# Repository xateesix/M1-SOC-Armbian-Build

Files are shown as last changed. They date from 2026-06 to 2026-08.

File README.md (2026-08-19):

# A3D M1 Pro X1  -  Armbian eMMC Firmware (RK3308BS)

**v0.64.1**  -  experimental firmware for the Artillery M1 Pro S1-SOC control board.

## Project intent

Turn an **otherwise barely usable or unusable** Artillery M1 Pro X1 into a **current mainline Klipper** printer by splitting roles across **new motion hardware** and the **factory S1-SOC board**.

| Role | Hardware | Target software |
|---|---|---|
| **Printer / motion (heavy lifting)** | New **host + CNC Mainboard with new toolhead board** (e.g. [BTT Manta M4P](https://www.biqu.equipment/products/bigtreetech-manta-m4p) + [FYSETC H36](https://www.fysetc.com/products/fysetc-h36-mainboard)) | Mainline **Klipper** on the MCU stack  -  motion, heaters, fans, probe |
| **Display + camera node** | Factory **RK3308 S1-SOC** (this firmware) | **KlipperScreen** on the stock LCD, **Crowsnest** for webcam streaming |

The S1-SOC is **not** the printer MCU. It is an **external companion**  -  UI and camera  -  while the new host + toolhead boards run Klipper for the machine.

This is a **work in progress** [incomplete] (Z-stop/probe on the motion stack, KlipperScreen/Crowsnest integration on the S1-SOC).

> ## WARNING  -  READ FIRST
>
> - **Experimental**  -  not supported by Artillery 3D; no warranty.
> - **Void warranty**  -  flashing and hardware mods void manufacturer warranty.
> - **Dangerous voltages**  -  mains AC and 24 V DC. Fire and shock risk.
> - **Extra hardware**  -  USB-C **data** cable, USB-TTL serial adapter (FT232RL), Windows PC with RKDevTool, MASKROM recovery access, plus the **host + toolhead upgrade** for printer control.
> - **You assume all risk**  -  authors are not liable for damage or injury.
>
> Full text: [`docs/WARNING.md`](docs/WARNING.md)

> **Hardware upgrade required for printing:** Motion and Klipper MCU duties need a **3/4-axis host** and **toolhead board** (see below). This S1-SOC image is for the **companion display/camera node**. Repinning JST connectors and high-voltage work can **destroy hardware** or **cause fire**. See [`docs/UPGRADE_PATH.md`](docs/UPGRADE_PATH.md).

## Target architecture (read before flash)

### Motion stack (required for Klipper printing)

| Part | Example |
|---|---|
| **Host** (3 or 4 axis + Klipper MCU) | [BIGTREETECH Manta M4P](https://www.biqu.equipment/products/bigtreetech-manta-m4p) |
| **Toolhead / CNC board** | [FYSETC H36](https://www.fysetc.com/products/fysetc-h36-mainboard) |

This combo does the **heavy lifting**  -  steppers, hotend, bed, probe, and mainline Klipper firmware on the MCU.

**Work in progress:** **Z-stop / Z-probe** still required. Current direction: **Sovol Eddy** in a **custom housing** on the front print head cover. The H36 is chosen for high-temp rating, **3-wire PWM** fan headers, enough GPIO for current and future hardware, and [hopefully] **sideways fit** inside the print head cover.

Details: [`docs/UPGRADE_PATH.md`](docs/UPGRADE_PATH.md).

### 3D printed parts (required for rebuild)

| Part | STEP model |
|---|---|
| Manta M4P mounting bracket | [`models/M4P_M1Pro_Mounting_bracket.step`](models/M4P_M1Pro_Mounting_bracket.step) |
| Power supply relocate bracket | [`models/M1-PowerSupply-Relocate.step`](models/M1-PowerSupply-Relocate.step) |

Print from the STEP files or export STL in your CAD tool. Details: [`docs/UPGRADE_PATH.md`](docs/UPGRADE_PATH.md).

### S1-SOC companion (this repository)

Flash this repo's image on the **factory S1-SOC** to drive:

- **KlipperScreen** on the built-in **480x272** display
- **Crowsnest** for USB webcam streaming to your Klipper stack

The companion talks to your **real Klipper host** (Moonraker on the Manta side) over the network. It does **not** replace the motion boards.

Configuration guide (KlipperScreen  ->  Moonraker IP, Crowsnest on companion, Mainsail/Fluidd webcam URL): [`docs/COMPANION_SETUP.md`](docs/COMPANION_SETUP.md).

Skilled **JST repinning**, **mains / 24 V** awareness, and acceptance of serious risk are required. See [`docs/WARNING.md`](docs/WARNING.md).

## What this is

Experimental **Armbian eMMC firmware** for the **RK3308BS S1-SOC** on the Artillery M1 Pro X1. It replaces the factory Linux image with a lean OS intended as a **KlipperScreen + Crowsnest companion node**, using the stock display and WiFi.

This repository provides the **companion-board firmware and build pipeline**, not the main Klipper MCU firmware for the Manta/H36 stack.

## Media (in this repository)

| Asset | File |
|---|---|
| Hardware overview video (~45 MB) | [`Media/VID_20260615_141308204.mp4`](Media/VID_20260615_141308204.mp4) |
| Boot logo source (BMP) | [`Media/boot-logo-artillery.bmp`](Media/boot-logo-artillery.bmp) |

The custom boot logo is compiled into boot assembly by `tools/build-armbian-bootimg.sh`.

Board overview and control-header pin identification (case light bar, RGB JST, +LED-).
## USB-C data cable (required for flash)

MASKROM flashing and RKDevTool need a **data-capable** USB connection from your PC to the control board USB port.

| Need | Detail |
|---|---|
| **Cable** | Good-quality **USB-C data cable** (USB-C to USB-A or USB-C, matching your PC) |
| **Not sufficient** | Charge-only cables, many cheap phone cables, or long/under-spec cables |
| **Symptom if wrong** | RKDevTool never sees the device, or download fails mid-flash |

Use a cable rated for **data + power**. Short, branded or known data cables are more reliable than generic charge cords. If flash is unstable, try another cable and USB port before changing firmware.

## RKDevTool (required on Windows)

Rockchip firmware flash and the final eMMC **pack** step both use **RKDevTool** on a **Windows PC**. This repository does not bundle RKDevTool.

| Need | Detail |
|---|---|
| **Tool** | RKDevTool (v2.86 or newer recommended)  -  includes `RKDevTool.exe` for flashing and `bin/AFPTool.exe` + `bin/RKImageMaker.exe` for packing |
| **Driver** | Rockchip USB driver via **DriverAssistant** (install before first flash) |
| **Use** | **Upgrade Firmware** tab with a monolithic `.img` (not balenaEtcher / raw `dd`) |
| **USB cable** | Good-quality **USB-C data cable** (see section above) |
| **Recovery** | Board in **MASKROM** (recovery button / maskrom pads + USB) |

**Download and documentation:**

- **Firefly** (ROC-RK3308-CC / RK3308): [Resource downloads (RKDevTool)](https://en.t-firefly.com/doc/download/53.html)  -  [Burning firmware guide](https://wiki.t-firefly.com/en/ROC-RK3308-CC/burning_firmware.html)
- **Radxa** (Rockchip tools): [RKDevTool documentation](https://docs.radxa.com/en/zero/zero3/low-level-dev/rkdevtool)  -  [Windows tools download](https://dl.radxa.com/tools/windows/) (`RKDevTool_Release_v2.86.zip`, `DriverAssistant`)

After installing, run `RKDevTool.exe` as Administrator. Flash steps: [`FLASH_RKDEVTOOL.md`](FLASH_RKDEVTOOL.md).

## USB serial adapter (recommended)

A **USB to TTL serial adapter** lets you see boot logs and log in when WiFi or the display are not set up.

| Need | Detail |
|---|---|
| **Adapter** | FTDI **FT232RL** USB-TTL (3.3 V logic)  -  e.g. [DSD TECH SH-U09C](https://www.amazon.com/DSD-TECH-Adapter-FT232RL-Compatible/dp/B07BBPX8B8) |
| **Level** | Set adapter jumper to **3.3V** (RK3308 UART is 3.3 V TTL) |
| **Wiring** | GND  ->  GND, adapter TXD  ->  board RX, adapter RXD  ->  board TX (UART3 header) |
| **Baud** | **1500000** |
| **Console** | **`ttyS3`** on recovered v67 artifacts (older factory notes mention `ttyFIQ0`) |

Use PuTTY, Tera Term, or `picocom` at **1500000 8N1**. FTDI VCP drivers: [ftdichip.com](https://ftdichip.com/drivers/vcp-drivers/).

Full wiring and terminal notes: [`docs/SERIAL_CONSOLE.md`](docs/SERIAL_CONSOLE.md).

## Download and flash (companion image)

Host-role rule: if build and flash are on different machines, upload the image to the flashing machine first and run flash there. Do not run `upgrade_tool` or `rkdeveloptool` on the build machine.

1. From **GitHub Releases**, download `rk3308bs-1.0.0-emmc-fixed-v64.img`

Release: [v0.64.1](https://github.com/xateesix/M1-SOC-Armbian-Build-scripts-public/releases/tag/v0.64.1) — `rk3308bs-1.0.0-emmc-fixed-v64.img` and `build-artifacts-v0.64.1.tar.gz`.
2. Flash with RKDevTool  ->  **Upgrade Firmware**
3. **Change the default password** on first login

| Account | Username | Default password |
|---|---|---|
| Normal user | `m1prox1` | `m1prox1` |
| Root | `root` | `m1prox1` |

WiFi is **not** configured on the published image; build-time preconfigure is optional.

Release assets: [`docs/RELEASE.md`](docs/RELEASE.md)

## Build from source (GPL / customization)

Source code and build scripts are in this repository. Large binaries are on **GitHub Releases** as `build-artifacts-v0.64.1.tar.gz`.

The v64 pipeline **repatches and repacks** those inputs for the **S1-SOC companion image**.

### Build requirements

| Component | Notes |
|---|---|
| **Linux / WSL2** | Ubuntu recommended  -  patch, boot build, staging |
| **Windows + RKDevTool** | Final pack step  -  see RKDevTool section above |
| **Serial** | USB-TTL adapter (FT232RL, 3.3 V)  -  see section above |

### Steps

```bash
git clone <this-repository-url>
cd <repository-directory>

./configure.sh
bash setup-validate.sh
bash tools/build-release-v64.sh
```

Output: `releases/1.0.0/rk3308bs-1.0.0-emmc-fixed-v64.img`

### What the scripts verify

| Script | Role |
|---|---|
| `install-build-deps.sh` | Host packages and tools |
| `fetch-build-sources.sh` | Release tarball inputs |
| `preflight-v64.sh` | Linux deps + tarball |
| `setup-validate.sh` | Runs `preflight-v64.sh` |

## Configuration

| File | Purpose |
|---|---|
| `config.env.example` | Defaults  -  safe to commit |
| `configure.sh` | Interactive `config.env` setup |
| `config.env` | **Local only**  -  never commit |

## Feature status (v0.64.1)

| Feature | Status |
|---|---|
| S1-SOC companion image (boot, display, serial, WiFi base) | Working / WIP |
| 480x272 display + boot logo | Working |
| Serial `ttyS3` @ 1500000 | Working (older factory notes mention `ttyFIQ0`) |
| WiFi (RTL8189FS) | On-device or custom rebuild |
| **KlipperScreen** (companion role) | Target  -  integration WIP |
| **Crowsnest** (companion role) | Target  -  integration WIP |
| Main Klipper MCU (Manta M4P + H36) | **Required separate upgrade**  -  not this image |
| Z-stop / bed probe (motion stack) | **WIP**  -  Sovol Eddy + custom cover mount |
| Case light bar (+LED-) | Pin identified; driver in progress |
| RGB pebbles (WS2812) | Not supported |
| Factory Makerbase UI | Not included |

GPIO map: [`docs/GPIO_AND_HARDWARE.md`](docs/GPIO_AND_HARDWARE.md)
Boot logo: [`docs/BOOT_LOGO.md`](docs/BOOT_LOGO.md)

The image build now stages KIAUH, Klipper, Moonraker, KlipperScreen, and Crowsnest source trees during rootfs customization.

## Build pipeline

```text
configure.sh  ->  config.env (BUILD_ARTIFACTS_URL)
fetch-build-sources.sh  ->  tarball + partition templates
preflight-v64.sh  ->  verify Linux deps + inputs

build-release-v64.sh
  |-- build-boot-v64.sh
  |-- patch-rootfs-v64-debugfs.sh
  |-- stage-pack-v64.sh
  -- windows-pack-update.ps1
```

## Repository layout

| Path | Description |
|---|---|
| `configure.sh` | Interactive configuration |
| `setup-validate.sh` | Pre-build verification |
| `tools/` | v64 companion image build scripts |
| `patches/` | Kernel and DTS patches (GPL) |
| `models/` | Required 3D printed bracket STEP files |
| `docs/` | User documentation |
| `releases/` | Build output (git-ignored) |

## License and disclaimer

GPL-licensed components remain under their respective licenses. Provided as-is for research and self-hosting. Not affiliated with Artillery 3D.

## Changelog

See [`CHANGELOG.md`](CHANGELOG.md).

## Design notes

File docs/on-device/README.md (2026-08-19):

# On-device documentation (v0.64.1)

Companion firmware for the Artillery M1 Pro X1 S1-SOC (RK3308BS). Additional guides are in this folder.

## Login credentials

Change passwords after first boot.

| Account | Username | Password |
|---|---|---|
| Normal user | `m1prox1` | `m1prox1` |
| Root | `root` | `m1prox1` |

WiFi is **not** pre-configured on the published image.

## Repository media

| Asset | Path on SD/eMMC |
|---|---|
| Hardware overview video | Not on device — see repo [`Media/VID_20260615_141308204.mp4`](https://github.com/xateesix/M1-SOC-Armbian-Build-scripts-public/blob/main/Media/VID_20260615_141308204.mp4) |

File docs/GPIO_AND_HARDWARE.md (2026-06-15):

# GPIO map

Confirmed: case light bar = GPIO2_B3 (gpiochip2 line 11, gpio75), 24 V enable.
RGB NeoPixel: not supported v0.64.1.
Serial console: ttyFIQ0 @ 1500000  -  see docs/SERIAL_CONSOLE.md.

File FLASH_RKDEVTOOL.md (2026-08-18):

# RK3308BS  -  RKDevTool flash guide (Artillery M1 Pro S1-SOC)

## Host role rule (mandatory)

- Build host and flash host are different roles.
- Never run `upgrade_tool` or `rkdeveloptool` on the build host.
- Always upload firmware image from build host to flash host first, then flash on flash host.

Linux flash-host example (SSH alias `flashpc`):

```bash
IMG="rk3308bs-1.0.0-v64-from-source-linux-emmc.img"
SRC="/home/xateesix/scratch/Projects/rk3308bs-workspace/M1-SOC-Armbian-Build/releases/v64-from-source-linux/$IMG"

rsync --partial --append-verify "$SRC" flashpc:~/rk3308bs-firmware/
ssh flashpc "sha256sum ~/rk3308bs-firmware/$IMG"
ssh flashpc "sudo upgrade_tool uf ~/rk3308bs-firmware/$IMG"
```

## Install RKDevTool (not included in this repo)

Use a **Windows PC**. Download RKDevTool and the Rockchip USB driver from vendor tool pages:

| Source | Links |
|-----|----|
| **Firefly** | [RKDevTool download](https://en.t-firefly.com/doc/download/53.html)  -  [ROC-RK3308-CC burning guide](https://wiki.t-firefly.com/en/ROC-RK3308-CC/burning_firmware.html) |
| **Radxa** | [RKDevTool docs](https://docs.radxa.com/en/zero/zero3/low-level-dev/rkdevtool)  -  [Windows tools](https://dl.radxa.com/tools/windows/) |

Recommended: `RKDevTool_Release_v2.86.zip` plus **DriverAssistant**. Install the driver first, then run `RKDevTool.exe` as Administrator.

## USB cable

Use a **good-quality USB-C data cable** between the PC and the board USB port. Charge-only or poor cables often prevent MASKROM detection or cause failed downloads. Try a short, known data cable and a direct motherboard USB port if RKDevTool does not see the device.

## Use Upgrade Firmware + monolithic `.img`

1. Enter **MASKROM** (recovery button / maskrom pads + USB).
2. Open **RKDevTool**.
3. Tab: **Upgrade Firmware** (second tab).
4. **Firmware:** browse to a single monolithic `.img` file.
   - Do **not** load a custom `config.cfg` with separate partition files.
   - Do **not** use **Advanced  ->  Write by address**.
5. Click **Upgrade** / **Run**.
6. Watch the log  -  you **must** see:
   - `Download Boot Success`
   - `Download IDB Success`
   - `Download Firmware Start` with **`Gpt=1`**
   - `Start to download rootfs, offset=0x...` (multi-minute write for large images)
   - `Download Firmware Success` (ret=0, not `ret=1`)
7. Unplug USB, power cycle.

If **Download Boot** fails to start:

- **Advanced**  ->  **Download Loader**  ->  use `MiniLoaderAll.bin` from your partition templates or factory extract
- Immediately repeat step 5 on **Upgrade Firmware** with the **full** `.img`.

---

## Factory reference image

Known-good monolithic package (use for recovery and as packaging reference):

```
KLP_IMG_ARTILLERY_M1_PRO_S1-SOC_20251126_Beta (1)/KLP_IMG_ARTILLERY_M1_PRO_S1-SOC_20251126_Beta.img
```

Unpacked structure matches our repacks:

| Component | Factory | Our repacks |
|---|---|---|
| `boot.bin` (MiniLoader) | 321870 bytes | **identical** |
| `package-file` layout | standard Rockchip | **identical** |
| `parameter.txt` | `TYPE: GPT`, `MAGIC: 0x5041524B` | same format |
| RKImageMaker wrap | `-RK3308` + `-os_type:androidos` | same (`windows-pack-update.ps1`) |

If factory `.img` works on Upgrade but a custom `.img` does not, the problem is **not** the tab  -  check the log for the failure patterns below.

---

## Images

| File | When to use |
|---|---|
| `KLP_IMG_ARTILLERY_..._Beta.img` | **Recovery**  -  known-good factory |
| `SMOKE_v2_repack_only.img` | Validate repack pipeline (factory contents) |
| `rk3308bs-1.0.0-emmc-fixed.img` | Symlink/copy of **latest built** `-vNN.img` (currently **v43** if v45 not built yet) |
| `rk3308bs-1.0.0-emmc-fixed-v43.img` | **Do not use**  -  rootfs baked with `debugfs set_inode_field`  ->  `bogus i_mode` login loop |
| `rk3308bs-1.0.0-emmc-fixed-v45.img` | **Build this next**  -  safe chroot + `/boot/system.cfg` (no v44 image was ever produced) |
| `rk3308bs-1.0.0-emmc-fixed-v42.img` | Last good kernel/display before v43 rootfs patch (no WiFi grow stack) |
| `rk3308bs-1.0.0-emmc-fixed-v14.img` | Old baseline  -  v13 thermal + built-in DRM, no custom WiFi/LCD module load |
| `rk3308bs-1.0.0-emmc-fixed-v13.img` | v11 serial + factory RK3308BS TSADC  -  **do not use** (reboot breaks GPT; LCD blank) |
| `rk3308bs-1.0.0-emmc-fixed-v12.img` | v11 serial + **no thermal emergency reboot** (soc-crit passive workaround) |
| `rk3308bs-1.0.0-emmc-fixed-v11.img` | Factory DTB + ttyS3 serial  -  **still thermal reboot loop on 6.18** |

**Do not use an old `-emmc-fixed.img` from before 2026-06-11**  -  those had a broken `boot.img` header (resource.img in wrong slot  ->  U-Boot PXE/`=>` prompt).

Factory GPT layout (reference):

| # | LBA | Size | Name |
|---|-----|---|---|
| 1 | 0x2000 | 0x1000 | uboot |
| 2 | 0x3000 | 0x1000 | trust |
| 3 | 0x4000 | 0x800 | misc |
| 4 | 0x4800 | 0xa000 | recovery |
| 5 | 0xe800 | 0x4800 | boot (9 MB factory) |
| 6 | 0x13000 | grow | rootfs |

The `-fixed` Armbian image expands boot to **17 MB** (`0x8a00`) and moves rootfs to `0x17200`  -  required for Armbian 6.18 `boot.img`. Upgrade with `Gpt=1` rebuilds GPT from `parameter.txt` inside the package.

---

## Working flash log (June 4  -  factory, Upgrade tab)

```
Download Boot Success
Download IDB Success
Download Firmware Start
  Gpt=1, DirectLBA=1
  Start to download trust, offset=0x3000
  Start to download uboot, offset=0x2000
  Start to download boot,   offset=0xe800
  Start to download rootfs, offset=0x13000   Ã¢â€ Â ~5 GB, several minutes
  Start to download recovery, offset=0x4800
  Start to download misc, offset=0x4000
Download Firmware Success
Reset Device Success
```

---

## Broken flash patterns (June 9  -  do NOT do this)

### Pattern A  -  Write by address / custom config

```
Download parameter at 0x00000000 ...     Ã¢â€ Â destroys GPT at LBA 0
RunProc is ending, ret=1
ERROR: GetParameter_Loader->Check parameter tag failed!
```

Cause: **Advanced  ->  Write by address**, or a `config.cfg` that lists `parameter`, `uboot`, `boot`, etc. as separate files instead of one monolithic `.img`.

### Pattern B  -  partial partition list without Gpt=1

```
Download uboot at 0x00002000 ...
Download trust at 0x00003000 ...
Download boot at 0x0000e800 ...
Download armbian-serial-soc at 0x00000000 ...   Ã¢â€ Â wrong item at LBA 0
RunProc is ending, ret=1
```

Cause: custom config pointing at loose `.img`/`.bin` files (not the monolithic update package).

### Pattern C  -  flash too fast

Flash finishes in under ~30 seconds on a multi-GB image  ->  only loader/IDB written, not full firmware.

---

## What each symptom means

| Symptom | Cause |
|---|-----|
| Instant MASKROM, no button | IDB / boot sectors corrupt (bad or partial flash) |
| No partition table in MASKROM | GPT never created (`Gpt=1` path not run) |
| U-Boot `=>` + pxelinux / PXE | Boot partition empty, **truncated boot.img**, or **broken boot.img header** |
| `boot partition is not enough to save image!` | Use `rk3308bs-1.0.0-emmc-fixed.img` (17 MB boot slot) |

---

## Serial

After successful recovered v67 flash: **UART3 @ 1500000**, console **`ttyS3`** (older factory notes mention `ttyFIQ0`).

Verify:

```bash
cat /etc/rk3308bs-release
```

---

## PXE / `=>` prompt after Armbian flash (troubleshooting)

That output means **U-Boot never started the kernel**  -  it is not a rootfs issue yet.

### If you see MASKROM loader output (`Code check error -1`, `tag:LOADER error`)

**Cause:** `rk3308bs-1.0.0-emmc-fixed-v4.img` patched `uboot.img` and broke Rockchip's hash check. **Do not use v4.**

**Recovery:**

1. MASKROM  ->  flash **factory** `KLP_IMG_ARTILLERY_..._Beta.img` (full ~5 GB)
2. Then flash **`rk3308bs-1.0.0-emmc-fixed-v11.img`** (or `rk3308bs-1.0.0-emmc-fixed.img`  -  same as v11)

### `Invalid DTB hash !` / `No valid DTB, ret=-22`

**Cause:** Custom `rk-kernel.dtb` was injected into `resource.img` without updating the RSCE SHA1 entry. U-Boot (`CONFIG_ROCKCHIP_DTB_VERIFY`) rejects the DTB before loading the kernel.

**Fix:** Use **`rk3308bs-1.0.0-emmc-fixed-v6.img`** or newer. v6 rebuilds `boot.img` with correct DTB hash + size in `resource.img`.

Serial symptom (v5 and earlier):

```
DTB: rk-kernel.dtb
HASH(c): error
Invalid DTB hash !
Failed to load android image
```

After v6+ you should see `HASH(c): OK`. If boot then **loops** with overlap/`overwritten` errors, flash **v7** (see below).

### Boot loop: kernel overlaps FDT (`Sysmem Error` / `image overwritten`)

**Cause:** Armbian 6.18 decompresses to ~40 MiB starting at `0x00280000`, but factory U-Boot places the FDT at `fdt_addr_r=0x01f00000` (~31 MiB). The kernel clobbers the device tree  ->  U-Boot resets  ->  loop.

Serial symptom (v6):

```
HASH(c): OK
Booting LZ4 kernel at 0x02480000(Uncompress to 0x00280000) with fdt at 0x01f00000
Sysmem Error: "UNCOMP_KERNEL" ... overlap with existence "FDT" (0x01f00000 ...)
ERROR: new format image overwritten - must RESET the board to recover
```

**Fix:** Flash **`rk3308bs-1.0.0-emmc-fixed-v7.img`** (v6 boot + patched `uboot.img` memory map **with corrected LOADER hash**). v4 had the same env patch but a broken hash (`Code check error -1`); v7 adds the `hash_by_crypto` value the MiniLoader expects.

Expected after v7:

```
HASH(c): OK
... with fdt at 0x05000000
Starting kernel ...
```

### Kernel panic: `Unable to mount root fs on unknown-block(0,0)`

**Cause:** Rockchip U-Boot passes **`/chosen/bootargs` from the DTB** to Linux, not the `boot.img` header cmdline. Custom DTB only had `console=`  -  no `root=PARTUUID=...`  -  so the kernel panics even though boot succeeds.

Serial symptom (v7):

```
Kernel command line: ... console=ttyS3,1500000n8
VFS: Cannot open root device "" or unknown-block(0,0)
Kernel panic - not syncing: VFS: Unable to mount root fs
```

Partition list shows rootfs at **`mmcblk0p6`** / **`614e0000-0000-4b53-8000-1d28000054a9`**  -  the data is there; the kernel just wasn't told where to mount.

**Fix:** Flash **`rk3308bs-1.0.0-emmc-fixed-v8.img`** (v7 + DTB `bootargs` with `root=PARTUUID=614e0000-0000-4b53-8000-1d28000054a9 rootfstype=ext4 rw rootwait`).

Expected after v8:

```
Kernel command line: ... root=PARTUUID=614e0000-0000-4b53-8000-1d28000054a9 rootfstype=ext4 rw rootwait
EXT4-fs (mmcblk0p6): mounted filesystem with ordered data mode
```

### Boot loop after Ã¢â‚¬Å“Welcome to ArmbianÃ¢â‚¬Â (`Temperature too high`)

**Cause:** Custom DTB (v8) is missing the factory **`/otp`** node used to calibrate the TSADC. The sensor reads too hot  ->  instant critical trip  ->  `reboot: HARDWARE PROTECTION shutdown`  ->  loop. v8 otherwise works (root mounts, systemd starts).

Serial symptom:

```
Welcome to Armbian-unofficial 26.08.0-trunk bookworm!
thermal thermal_zone1: soc-thermal: critical temperature reached
reboot: HARDWARE PROTECTION shutdown (Temperature too high)
```

**Fix (serial + root):** v8/v11 bootargs and ttyS3. **Thermal loop:** use **v13** (proper TSADC) or **v12** workaround (passive soc-crit).

**Do not** run manual `saveenv` unless v7 still fails  -  v7+ bakes the memory layout into default env.

### No serial output / boot loop (v9 - v10)

**Cause:** Factory DTB **disables** `serial@ff0d0000` and routes UART3 through **fiq-debugger** (`console=ttyFIQ0`). That works on factory kernel **5.10**, but **Armbian 6.18 does not ship fiq-debugger**  -  so neither `ttyFIQ0` nor `ttyS3` works after `earlycon`, and the serial port goes silent while the board keeps resetting (thermal/display activity may still occur).

v8 had serial because the **custom DTB** enabled `serial@ff0d0000` + `console=ttyS3` (but lacked factory OTP  ->  thermal loop).

**Fix:** Flash **`rk3308bs-1.0.0-emmc-fixed-v11.img`**  -  factory DTB (OTP/thermal) with **fiq-debugger disabled**, **`serial@ff0d0000=okay`**, **`console=ttyS3,1500000n8`**. Same UART header @ **1500000**.

**Note:** v11 serial works, but Armbian **6.18** still hits `soc-thermal: critical temperature reached` ~1 s after boot (factory `/otp` in DTB is not enough for mainline TSADC trim). See **v12** below.

Expected after **v13** (preferred) or **v12** (workaround):

```
Kernel command line: ... console=ttyS3,1500000n8 root=PARTUUID=614e0000-0000-4b53-8000-1d28000054a9 ...
Welcome to Armbian-unofficial ...
rk3308bs login:
```

On **v13**, also check idle temperature is sane (not instant critical trip):

```
cat /sys/class/thermal/thermal_zone0/temp
# expect ~30000 - 50000 (millidegrees C) at room temp
```

### Thermal reboot ~1 s after boot (v8, v11)

**Cause:** TSADC reads too hot without mainline OTP trim  ->  instant **critical** trip  ->  `reboot: HARDWARE PROTECTION shutdown (Temperature too high)`  ->  looks like a very fast boot loop. Serial **does** work on v11 (full dmesg through USB/MMC init, then reboot at ~1 s).

```
thermal_sys: No trip points found for tsadc id=1
thermal thermal_zone0: soc-thermal: critical temperature reached
reboot: HARDWARE PROTECTION shutdown (Temperature too high)
```

v8 reached `Welcome to Armbian` first (custom DTB, no factory OTP) then the same thermal shutdown. v9 - v11 kept factory OTP in DTB but **6.18** still reboots early.

**Fix:** Flash **`rk3308bs-1.0.0-emmc-fixed-v13.img`**  -  factory DTB + ttyS3 + kernel **`rockchip,rk3308bs-tsadc`** linear conversion (see **`THERMAL_RK3308BS.md`**).

**Workaround (no kernel rebuild):** **`rk3308bs-1.0.0-emmc-fixed-v12.img`**  -  same as v11 but **`soc-crit` downgraded to passive** so Linux does not emergency-reboot (readings still wrong; trips disabled).

### Armbian 6.18 kernel + factory U-Boot memory layout (manual fallback)

Factory `uboot.img` only leaves ~25 MiB for a decompressed kernel (`kernel_addr_r=0x00680000`, `fdt_addr_r=0x01f00000`). Armbian 6.18 is larger  ->  `boot_android` fails  ->  PXE/`=>`.

**Manual fallback only** (v5/v6 at `=>` with `bootdelay` > 0). v7 should not need this:

```
setenv fdt_addr_r 0x05000000
setenv kernel_addr_r 0x02080000
setenv kernel_addr_c 0x08000000
saveenv
reset
```

If `saveenv` succeeds, the next boot should load the kernel (watch for Linux messages, not PXE).

### Checklist (normal flash path)

1. **Factory recovery first**  -  flash `KLP_IMG_ARTILLERY_..._Beta.img` (full ~5 GB, `rootfs @ 0x13000`). Confirm the board boots factory again.

2. **Flash the fixed Armbian image**  -  **`rk3308bs-1.0.0-emmc-fixed-v14.img`** (v7 uboot + v14 boot/kernel + reboot-safe rootfs).  
   **Never** use `-v4.img` (patched uboot **without** hash fix  -  bricks at loader).  
   **Avoid v13** after first boot  -  Armbian resize corrupts fixed GPT (see below).

3. **Read the RKDevTool log**  -  both lines are required:
   ```
   Start to download boot, offset=0xe800, size=14630912
   Start to download rootfs, offset=0x17200, size=1647312896
   ```
   (v12 used `size=18040832` for boot  -  still valid if you flash v12. Boot must fit the 17 MiB partition.)
   If `rootfs` is missing (log shows `total=33613312` only), the rootfs partition is empty  -  see **Option B** in the main guide (Advanced  ->  write `rootfs.img` at **`0x17200`**).

4. **At the U-Boot `=>` prompt** (optional diagnosis):
   ```
   mmc dev 0
   mmc part
   ```
   Boot partition must be **~17 MiB** (not 9 MiB). If it still shows 9 MiB, parameter/GPT did not update  -  redo step 1, then step 2.

### Why this happens

| Cause | What happened |
|----|---|
| `Invalid DTB hash` | Custom DTB in `resource.img` without RSCE SHA1 update (fixed in v6+) |
| Boot loop / `image overwritten` | Kernel decompress overlaps FDT at `0x01f00000` (fixed in v7 uboot env + hash) |
| Kernel panic `unknown-block(0,0)` | DTB missing `root=PARTUUID=...` in `/chosen/bootargs` (fixed in v8+) |
| Thermal reboot (~1 s or after banner) | TSADC uncalibrated on Armbian 6.18 (fix: v13+ RK3308BS linear TSADC; workaround: v12 passive soc-crit) |
| Reboot hang / kernel panic after first boot | `armbian-resize-filesystem` expanded rootfs GPT on eMMC  -  U-Boot shows empty part 5 name and wrong size; fixed in **v14** (`/root/.no_rootfs_resize`) |
| Blank LCD after Linux | DRM built as modules but not installed (v13); fixed in **v14** (built-in `CONFIG_DRM_ROCKCHIP=y`) |
| Silent serial / boot loop on v9 - v10 | Factory DTB disables UART3 unless fiq-debugger works (Armbian 6.18 has none)  -  fixed in v11 |
| `Code check error -1` | Patched uboot without LOADER hash update (v4; fixed in v7) |
| Old `-emmc-fixed.img` | `boot.img` had `resource.img` in ramdisk slot instead of second slot  ->  U-Boot rejects it |
| v43 `Authentication failure` / `bogus i_mode (644)` | Rootfs corrupted by `patch-rootfs-v17-debugfs.sh`. **Full flash v45** after building (not update over grown eMMC) |
| No v44 firmware | v44 script existed but **never built**  -  use `tools/build-release-v45-rootfs-only.sh` |
| Partial flash (`total=33613312`) | Boot written but rootfs skipped; GPT may not match |
| 9 MiB boot slot + 17 MiB boot.img | U-Boot reads truncated image  ->  same PXE symptom |

## Erase vs partition table (important)

**RKDevTool "Erase Flash" does NOT remove the GPT.** It wipes partition *data* (zeros flash blocks). The partition table layout often persists or is immediately **rebuilt** on the next flash.

| Action | GPT effect | Data effect |
|-----|---|---|
| **Erase Flash** (Advanced) | GPT usually **unchanged** | Partition contents zeroed |
| **Upgrade Firmware** + monolithic `.img` | **`Gpt=1` rebuilds GPT** from `parameter.txt` inside the image | Writes trust, uboot, boot, rootfs, etc. |
| **Factory full image** flash | Full GPT + all partitions | Clean baseline |

**Only Upgrade Firmware** (main tab) with a complete `rk3308bs-*.img` rebuilds GPT correctly *and* writes partition data. Erase alone is never enough.

### What your 12:30 flash did (Putty + RKDevTool log)

```
total=30342656          boot-only (~1 sec)  -  wrong image (v46 grow-only)
Gpt=1                   GPT rebuilt  ->  rootfs *name* appeared (grow size 0xe78ddf)
(no rootfs line)        rootfs *data* never written  ->  empty/corrupt rootfs
```

Putty then shows `LoadTrustBL error:-3` / `No find trust.img!`  -  trust area invalid after erase + incomplete flash.

### Correct recovery sequence

1. **Do not rely on Erase** to fix GPT  -  it will not clear the table.
2. MASKROM  ->  **Upgrade Firmware** (main tab, NOT Advanced write-by-address).
3. Select **`rk3308bs-1.0.0-emmc-fixed-v47.img`** (~1.68 GB).
4. **Before clicking Run**, confirm image file size ~1.6 GB on disk.
5. Log **must** show:
   ```
   total=1677655552
   Start to download rootfs,offset=0x17200,size=1647312896
   ```
   (~47 - 48 seconds for rootfs). If `total=30342656`, STOP  -  wrong image or wrong mode.
6. After success, GPT should show part 6 **rootfs** @ `0x17200` (size may display as grow `0xe78ddf`  -  OK if rootfs data was written).

### Putty logs

Save session logs to `C:\Workspaces\Putty-log\` for boot/flash verification.

## Boot hang at "clk: Disabling unused clocks"

**Symptom:** Serial stops after `clk: Disabling unused clocks`. No login, no panic.

**Cause:** eMMC (`mmc0`) never creates `mmcblk0`. Kernel blocks on `rootwait` for `PARTUUID=614e0000-...`.

Compare to factory dmesg (works):
```
mmc0 HS200 -> Waiting for root -> Successfully tuned phase -> mmcblk0 -> EXT4 mount
```

v48 PuTTY log (hangs):
```
mmc2: SD card detected (mmcblk2)   <- SD slot occupied
mmc0 HS200
(no "Successfully tuned phase")
(no mmcblk0)
clk: Disabling unused clocks
```

**Fix:** Remove the microSD card from the printer before boot. Factory images were tested with an empty SD slot. SD probe on `mmc@ff480000` (mmc2) can prevent eMMC tuning from completing.

**Verify after removing SD:**
- `dwmmc_rockchip ff490000.mmc: Successfully tuned phase to ...`
- `mmcblk0: mmc0:0001 ...`
- `EXT4-fs (mmcblk0p6): mounted filesystem`
- autologin on ttyFIQ0

SD slot can be used after boot for extra storage; avoid booting with a card inserted until we add a DT defer fix.

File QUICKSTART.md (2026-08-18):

# QUICKSTART.md

## 🚀 Build Your Firmware in 3 Steps

### Step 1: Configure (One-time)
```bash
cd Armbian

# Edit your settings
nano config.env
```

Save and close. Check these are filled in:
- `BUILD_SERVER_HOST` = your Ubuntu machine
- `WIFI_SSID` and `WIFI_PASSWORD`
- `ROOT_PASSWORD`

### Step 2: Validate
```bash
chmod +x setup-validate.sh
./setup-validate.sh
```

You should see: `✅ All Checks Passed!`

### Step 3: Build
```bash
chmod +x build-enhanced.sh
./build-enhanced.sh
```

Wait ~30 minutes. Image downloads when done.

---

## 📝 Output

After a successful build, you'll have:
- `Armbian-unofficial_*_rk3308bs-evb_jammy_*.img` in the Armbian folder
- WiFi pre-configured (SSID: YOUR_WIFI_SSID)
- Root password set (no interactive prompt)

---

## 💾 Flash to Device

### Windows
1. Download [balenaEtcher](https://www.balena.io/etcher/)
2. Open, select image + microSD card
3. Click "Flash"
4. Insert microSD into RK3308BS board

### Linux
```bash
sudo dd if=Armbian-*.img of=/dev/sdX bs=4M status=progress && sync
```

---

## 🔧 After Flashing

1. Insert microSD into board
2. Connect power + USB
3. Wait ~30 seconds for boot
4. Check WiFi: `ping google.com` (should work)
5. SSH as root:
   ```bash
   ssh root@BOARD_IP  # Password from config.env
   ```

---

## 📖 For More Info
- README.md - Full documentation
- IMPROVEMENTS.md - What changed & why
- GITHUB_SETUP.md - Optional GitHub sync

---

## ⚡ Tips

**Quick rebuild after editing DTS:**
```bash
./build-enhanced.sh kernel
```
(Much faster, ~25 min instead of 45)

**Change WiFi later:**
```bash
ssh root@BOARD_IP
nano /etc/netplan/01-rk3308bs-wlan0.yaml
netplan apply
```

**View build log:**
```bash
tail -f build-remote.log
```

---

**Stuck?** See README.md "Troubleshooting"

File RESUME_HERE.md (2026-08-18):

# Resume Here  -  RK3308BS Armbian (M1 Pro S1-SOC)

**Read this first** after a break, a failed build, or a new Cursor session.

## Project goal

Build a **distributable, reproducible, lean Armbian OS** for the Artillery M1 Pro S1-SOC (RK3308BS) that:

- **Fully supports onboard hardware**  -  LCD, touch, WiFi, serial, thermal, eMMC (everything needed on the printer)
- **Targets Klipper**  -  minimal rootfs, reliable boot, display + network for a printer host (not a general desktop)
- **Armbian-first by default**  -  normal first-boot user creation flow is the default. Optional pre-bake mode can inject username/password/WiFi from `config.env` when explicitly enabled.
- **Reproducible**  -  scripted pipeline from Armbian source  ->  patched rootfs  ->  monolithic eMMC image; same inputs produce the same output
- **Published publicly on GitHub**  -  `https://github.com/xateesix/M1-SOC-Armbian-Build.git` for others to fork, customize `config.env`, and build their own image

**Design principles:** lean (no bloat), hardware-complete, script-driven, config-driven, documented flash path. Current recovered baseline is the v67 thermal-fix packaging line reconstructed from surviving logs and artifacts after a lost agent session.

**Workspace assumption:** this environment is unstable; VS Code or the userspace may disappear at any time. Save durable state in tracked files and session artifacts, not only in live agent memory.

### Hardware support checklist (target state)

| Component | Status | Notes |
|---|---|---|
| eMMC boot/flash | Working | RKDevTool monolithic `.img`, 17 MB boot slot, Linux packer path recovered |
| Serial console | Reconfirm | Recovered v67 artifacts use UART3 @ 1500000 with **ttyS3** bootargs; older docs mention `ttyFIQ0` |
| 480x272 LCD | In progress | Factory boot path retained; on-device reconfirmation still needed |
| Goodix GT911 touch | Target | I2C3  -  verify on next v67 flash |
| RTL8189FS WiFi | In progress | Module baked; credentials from `config.env` |
| RK3308BS thermal | Recovered fix | Kernel patch `0002-thermal-rockchip-rk3308bs-tsadc.patch`; verify on-device again |
| Klipper host ready | Target | Lean Bookworm, SSH/serial login, WiFi, display |

### User customization (before compile)

Edit **`config.env`**  -  single file, no image editing:

| Setting | Variable |
|---|---|
| Username | `USER_NAME`, `USER_PASSWORD`, `USER_REALNAME` |
| Root password | `ROOT_PASSWORD` |
| WiFi | `WIFI_SSID`, `WIFI_PASSWORD`, `WIFI_COUNTRY` |
| Locale / timezone | `LOCALE`, `TIMEZONE` |
| Serial console | `SERIAL_GETTY`, `SERIAL_BAUD` |

For public GitHub: ship `config.env.example` with placeholders; keep real `config.env` local (see roadmap in `.cursor/STATE.md`).

Public exports must be sanitized: no usernames, passwords, Wi-Fi data, IPs, hostnames, serial logs, or proprietary firmware blobs.

## Workspace

| | Path |
|---|---|
| **Windows** | `C:\Workspaces\Armbian-M1-SOC` |
| **WSL** | `/mnt/c/Workspaces/Armbian-M1-SOC` |
| **Recovered Linux workspace** | `/home/xateesix/scratch/Projects/rk3308bs-workspace/M1-SOC-Armbian-Build` |
| **Linux flash host** | `flashpc` / `10.22.2.22` |
| **Git remote** | `https://github.com/xateesix/M1-SOC-Armbian-Build.git` |

**Deprecated (do not use):** `C:\Users\john.X86\Downloads\RKDevTool_Release_v2.86\...\Output\Armbian`

## Hardware

- Board: Artillery M1 Pro S1-SOC (RK3308BS)
- Flash tool: RKDevTool v2.86  ->  tab **Upgrade Firmware** (monolithic `.img` only)
- Serial: **UART3 @ 1500000**; recovered v67 artifacts currently use **`ttyS3`** (older factory notes mention `ttyFIQ0`)
- LCD: 480x272 RGB panel-dpi
- WiFi: RTL8189FS (`8189fs.ko`)

## Current firmware line

| Item | Value |
|---|---|
| **Target version** | **v67** (recovered thermal-fix line) |
| **Why v67** | Latest recovered eMMC artifact after the lost session; packaging completed on 2026-07-22 |
| **Thermal basis** | `0002-thermal-rockchip-rk3308bs-tsadc.patch` + rebuilt Armbian image |
| **Flash image** | `/home/xateesix/scratch/Projects/pack/releases/v67/rk3308bs-1.0.0-v67-emmc.img` |
| **Staging dir** | `/home/xateesix/scratch/Projects/pack/releases/v67/pack_input/` |

**Do not flash v43**  -  known `Authentication failure` / `bogus i_mode (644)`.

## Recovered state after lost session (2026-08-17)

1. Later work continued beyond the old v46 handoff; surviving artifacts show v64, v65, v66, and **v67** builds.
2. Latest recovered packaging success is logged in `output/smart-build/20260722-130656-2058017.summary.log`.
3. v67 succeeded via **Phase A factory boot.img cmdline patch** (`console=ttyS3,1500000n8` + root PARTUUID) and a 17 MB boot partition.
4. The full custom DTB/resource path hit a slot-size limit during recovery, so the final v67 artifact used the factory boot/resource path instead.
5. User-reported last lost-session outcome: successful eMMC image testing of the thermal management fix.
6. Linux flash host confirmed after recovery: **`flashpc` = `10.22.2.22`**.
7. **Next:** flash-test v67 again and record serial, LCD, Goodix, WiFi, and thermal behavior in `.cursor/STATE.md`.

## Quick commands

### Rebuild from source (current recovered path)

```bash
cd /home/xateesix/scratch/Projects/rk3308bs-workspace/M1-SOC-Armbian-Build
sudo -v
RELEASE_TAG=v68-next RK3308BS_TSADC=1 bash tools/build-from-source-linux.sh
# Re-pack an already staged release tag with Linux tools:
bash tools/pack-firmware-linux.sh v67 /home/xateesix/scratch/Projects/pack
```

### Flash (Windows)

1. MASKROM  ->  RKDevTool  ->  **Upgrade Firmware**
2. Copy `/home/xateesix/scratch/Projects/pack/releases/v67/rk3308bs-1.0.0-v67-emmc.img` to the Windows flash host and select that file in RKDevTool
3. Log must show `Gpt=1`, `Download rootfs`, `Download Firmware Success`

### Verify on board (serial @ 1500000, recovered v67 uses ttyS3)

```bash
cat /etc/rk3308bs-release
uname -r
lsblk
dmesg | grep -E 'mmc|drm|8189|tsadc'
cat /sys/class/thermal/thermal_zone0/temp
systemctl status serial-getty@ttyS3.service
```

## v67 packaging notes

Recovered v67 packaging keeps the factory-style `rootfs:grow` start at `0x17200`, expands boot to 17 MB, and patches the factory boot cmdline in place. This avoided the earlier GPT/mount problems and the later resource-slot overflow seen when trying to embed the larger custom DTB directly.

## Pipeline map (v67 recovered)

```
build-from-source-linux.sh      (injects 0001 DTS + 0002 thermal patch into Armbian build)
   ->  fresh Armbian image
build-emmc-release.sh --pack-only
   ->  rootfs.img + Phase A patched factory boot.img + pack_input/
pack-firmware-linux.sh
   ->  rk3308bs-1.0.0-v67-emmc.img
```

## Config (single source of truth)

Edit **`config.env`** before every build  -  this is how end users customize the distributable image:

| Setting | Variable |
|---|---|
| Username / password | `USER_NAME`, `USER_PASSWORD`, `ROOT_PASSWORD` |
| WiFi | `WIFI_SSID`, `WIFI_PASSWORD`, `WIFI_COUNTRY` |
| Locale / timezone | `LOCALE`, `TIMEZONE` |
| Serial console | `SERIAL_GETTY`, `SERIAL_BAUD` |

Default behavior keeps standard Armbian first-boot setup. To pre-bake credentials/WiFi, build with `--preconfigure-credentials` (or `PRECONFIGURE_CREDENTIALS=1`) and supply values via `config.env`.

## If something breaks

| Symptom | Likely cause | Fix |
|---|---|-----|
| Login loop / `bogus i_mode` | Flashed v43 or partial update over grown eMMC | **Do not use v43**; full flash recovered v67 |
| Silent serial | Wrong console or wrong baud | Recovered v67 uses **ttyS3 @ 1500000**; confirm before changing scripts |
| U-Boot `=>` / PXE | Truncated boot.img or bad header | Use monolithic v67 image with 17 MB boot slot |
| DTB/resource packing failure | Custom DTB exceeds factory resource slot | Use recovered Phase A factory boot path or shrink DTB |
| Thermal reboot loop | TSADC conversion mismatch | Rebuild with `0002-thermal-rockchip-rk3308bs-tsadc.patch` enabled |
| Blank LCD | DRM modules missing | Re-run module install script |
| Build can't find files | Old Downloads paths | Use scripts with `$SCRIPT_DIR` and current workspace paths |
| Missing monolithic pack output | Windows pack path drift or stale legacy tool path | Use `tools/pack-firmware-linux.sh` or verify `windows-pack-update.ps1` inputs |

## Key docs

| File | When to read |
|---|---|
| **RESUME_HERE.md** | This file  -  session pickup |
| **`.cursor/STATE.md`** | Machine-readable snapshot (update after builds) |
| **FLASH_RKDEVTOOL.md** | Flash failures, log patterns, version history |
| **EMMC_RELEASE.md** | Full Phase A/B pipeline |
| **THERMAL_RK3308BS.md** | TSADC / thermal issues |
| **config.env** | Credentials and build server |
| **QUICKSTART.md** | Fresh Armbian compile from Ubuntu server |

## After each successful build

Update **`.cursor/STATE.md`**:

- `last_build`, `firmware_version`, artifact paths, git commit, next step.

## Factory recovery

If board is bricked: flash factory `KLP_IMG_ARTILLERY_M1_PRO_S1-SOC_20251126_Beta.img`, then re-flash latest `-emmc-fixed-vNN.img`.

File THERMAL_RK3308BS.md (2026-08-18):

# RK3308BS thermal (TSADC)  -  factory vs Armbian 6.18

Your Artillery M1 Pro S1-SOC uses **RK3308BS** silicon (`chip_id:330800` in preloader; GRF chip ID **0x3308C**). The “SOC is barely warm but kernel reboots for temperature” bug is a **driver conversion-table mismatch**, not a broken sensor or missing flash.

## What factory firmware does (kernel 5.10)

Factory uses the vendor **`rockchip-thermal`** driver, not mainline as-shipped in vanilla 6.18.

| Piece | Factory behavior |
|---|---|
| DTB | `tsadc@ff1f0000` + `otp@ff210000` + `thermal-zones/soc-thermal` with 115°C **critical** trip |
| OTP in DTB | `cpu-leakage@17`, `logic-leakage@18`, `id@7`  -  used for **CPU OPP / cpuinfo**, **not** TSADC trim cells in the factory DTB |
| TSADC trim in DTB | **None**  -  no `trim_l` / `trim_h` / `trim` on the tsadc node |
| Driver secret | On probe, vendor code calls `soc_is_rk3308bs()` and **replaces** the chip profile with `rk3308bs_tsadc_data` |

Vendor `rk3308bs_tsadc_data` (Rockchip 5.10 `drivers/thermal/rockchip_thermal.c`):

- **Linear conversion**: `kNum = 2699`, `bNum = 2796` (not the rk3328 lookup table)
- **One channel** (`chn_num = 1`) for BS
- **No** `get_trim_code`  -  trim from OTP is not required for BS when using this table
- dmesg: `rockchip-thermal ff1f0000.tsadc: tsadc is probed successfully!`

So factory “handles it” by **BS-specific math inside the kernel**, not by extra OTP nodes in the DTB you already ship.

## What Armbian 6.18 does today

Armbian’s `rockchip,rk3308-tsadc` support (backport of mainline/rpardini work) uses:

- **`rk3328_code_table`** lookup  -  correct for RK3328, **wrong for RK3308BS**
- Mainline 6.18 **`chip_tsadc_table` has no `kNum`/`bNum`** (vendor still has them)
- Same factory DTB  ->  raw ADC codes map to **absurdly high °C**  ->  instant `soc-thermal: critical` (115°C) or hardware TSHUT (~120°C)

That is why v9 - v11 (“factory OTP DTB”) still rebooted, and why v12 (passive critical trip) boots.

## Proper fix (match factory behavior)

Requires a **kernel patch**, then rebuild `linux-image-current-rockchip64` (or full Armbian image). DTB-only changes cannot fix the conversion table. In this workspace, the canonical source fix is the recovered `patches/0002-thermal-rockchip-rk3308bs-tsadc.patch` path used by the v67 build line.

### Option A  -  Recommended (match vendor 5.10)

1. Patch `drivers/thermal/rockchip_thermal.c`:
   - Restore **`kNum` / `bNum`** in `struct chip_tsadc_table` and the linear paths in `rk_tsadcv2_code_to_temp` / `rk_tsadcv2_temp_to_code` (copy from Rockchip `develop-5.10`).
   - Add **`rk3308bs_tsadc_data`** with `kNum=2699`, `bNum=2796`, `chn_num=1`.
   - Either:
     - add compatible **`rockchip,rk3308bs-tsadc`**, or
     - on `rockchip,rk3308-tsadc` probe, read **GRF chip ID** at `0xff000800` and select BS table when ID is **0x3308C** (same as vendor `soc_is_rk3308bs()`).

2. Patch factory/resource DTB (optional): set tsadc compatible to `rockchip,rk3308bs-tsadc` if using separate compatible string.

3. **Remove** v12 `--disable-thermal-critical` so factory 115°C critical trip works again.

4. Rebuild boot.img + monolithic `.img`.

Patch template: `patches/0002-thermal-rockchip-rk3308bs-tsadc.patch` (apply under `userpatches/kernel/rockchip64-current/`).

### Option B  -  Workaround only (historical v12 stopgap)

- Keep `soc-crit` as passive / very high temp so Linux never emergency-reboots.
- Sensor readings in `/sys/class/thermal/` may still be nonsense; fine for Klipper if the board stays up.
- Hardware TSHUT may still exist if ADC reads stay above ~120°C  -  if you see reboot **after** `Welcome to Armbian`, next step is raising `rockchip,hw-tshut-temp` or disabling hw tshut in DTB.

## Verify after kernel fix

On serial (factory-style, should **not** trip at 1 s on a cold board):

```text
# cold boot, no "critical temperature reached" in first 5 s
cat /sys/class/thermal/thermal_zone0/temp   # expect ~30000 - 50000 (30 - 50°C) at idle
```

Compare with factory audit dmesg: `.cursor/rk3308_factory_audit/dmesg_full.txt` line 128  -  tsadc probes cleanly, no thermal panic.

## References in this repo

- Factory DTB: `factory_fresh/05_dts/rk3308-factory.dts` (`tsadc@ff1f0000`, `otp@ff210000`, trips)
- Factory dmesg: `.cursor/rk3308_factory_audit/dmesg_full.txt`
- v12 workaround: `tools/patch-dtb-bootargs.py --disable-thermal-critical`
- Board audit script (run on booted board): `RK3308_FACTORY_AUDIT.SH`

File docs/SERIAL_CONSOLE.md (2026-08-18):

# Serial console (UART debug)

Required for boot logs, login, and troubleshooting when display or network are not enough.

## Adapter

Use a **USB to TTL serial adapter** with a genuine **FTDI FT232RL** chip (stable drivers on Windows).

Example (tested): [DSD TECH SH-U09C on Amazon](https://www.amazon.com/DSD-TECH-Adapter-FT232RL-Compatible/dp/B07BBPX8B8) (model SH-U09C, FT232RL, includes Dupont cable).

| Requirement | Detail |
|---|---|
| Chip | FTDI FT232RL (or FT232RNL) recommended over CP2102/CH340 |
| Logic level | **3.3 V TTL**  -  set the adapter VCC jumper to **3.3V** (not 5V) |
| Pins used | **GND**, **TXD** (adapter  ->  board RX), **RXD** (adapter  ->  board TX) |
| Cable | Female-to-female Dupont jumpers (often included with the adapter) |

Do **not** connect adapter **VCC** to the board unless you intentionally need to power something; GND + TX + RX are enough for console.

## Board settings

| Setting | Value |
|---|---|
| Header | UART3 on the S1-SOC control board |
| Baud rate | **1500000** (not 115200) |
| Linux console | **`ttyS3`** on recovered v67 artifacts (older factory notes mention `ttyFIQ0`) |
| Data | 8N1, no flow control |

## PC terminal

| OS | Examples |
|----|---|
| Windows | PuTTY, Tera Term, or `putty -serial COMx -sercfg 1500000` |
| Linux / WSL | `picocom -b 1500000 /dev/ttyUSB0` or `minicom` |

Select the COM port assigned to the FTDI adapter. If the port does not appear, install drivers from [FTDI](https://ftdichip.com/drivers/vcp-drivers/).

## Safety

Printer mains and 24 V may be present on the board. Prefer debugging with **USB/network disconnected from the printer** when probing headers, or work only when qualified.

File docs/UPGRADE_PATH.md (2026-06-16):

# Host + toolhead upgrade and S1-SOC companion role

## Project goal

Make an Artillery M1 Pro X1 that is **barely usable or unusable** on the factory stack into a **current mainline Klipper** printer  -  not by running everything on the old RK3308 board, but with a **split architecture**.

| Role | Hardware | Software |
|---|---|---|
| **Motion / Klipper MCU** | New **host + CNC toolhead** | Mainline **Klipper** (heavy lifting) |
| **Display + camera** | Factory **S1-SOC** (RK3308) | **KlipperScreen**, **Crowsnest** |

The S1-SOC is an **external companion node**  -  stock LCD and network for UI and webcam  -  while the new boards control the printer.

**Status:** Work in progress. Z-stop/probe on the motion stack is unfinished. KlipperScreen and Crowsnest on the S1-SOC are targets for this firmware line.

## Motion stack (required)

| Role | Example hardware |
|---|---|
| **Main host** (3 or 4 axis + Klipper MCU) | [BIGTREETECH Manta M4P](https://www.biqu.equipment/products/bigtreetech-manta-m4p) |
| **Toolhead / CNC board** | [FYSETC H36](https://www.fysetc.com/products/fysetc-h36-mainboard) |

This pair runs **Klipper** for motion, heaters, fans, and (once complete) bed probing. The S1-SOC does **not** replace this stack.

## 3D printed parts (required for rebuild)

The motion-stack upgrade needs two **printed brackets** in the repository `models/` directory:

| Part | STEP file | Purpose |
|---|---|---|
| **Manta M4P mounting bracket** | [`M4P_M1Pro_Mounting_bracket.step`](../models/M4P_M1Pro_Mounting_bracket.step) | Mount the BTT Manta M4P inside the M1 Pro chassis |
| **Power supply relocate bracket** | [`M1-PowerSupply-Relocate.step`](../models/M1-PowerSupply-Relocate.step) | Relocate the factory PSU to clear space for the new host |

Print from the STEP source or export STL from your CAD tool before assembly.

## Why FYSETC H36 (example toolhead)

| Factor | Notes |
|---|---|
| **Temperature rating** | High-temp tolerance for enclosed / hot chamber use |
| **Fan headers** | Multiple **3-wire PWM** fan outputs (not 4-wire RGB) |
| **Expansion** | Enough headers for required and future hardware |
| **Mechanical fit** | Target **sideways** install inside the front print head cover (validation ongoing) |

## Z-stop / probing (work in progress)

Mainline Klipper on the motion stack still needs a reliable **Z reference**.

- **Sovol Eddy** probe
- **Custom housing** on the **front print head cover**
- Wired through the **Manta M4P + H36** stack (not the S1-SOC companion)

## What this repository is for

**Companion firmware** for the factory S1-SOC board:

- Lean **Armbian** on eMMC
- Built-in **480x272** display for **KlipperScreen** (target)
- Network services for **Crowsnest** (target)
- Talks to the **real Klipper host** (Moonraker on the Manta) over WiFi/LAN

It is **not** the Klipper MCU image for the Manta or H36.

Setup guide: [`COMPANION_SETUP.md`](COMPANION_SETUP.md)  -  KlipperScreen + Crowsnest on the S1-SOC, Moonraker on the Manta.

## If you modify harnesses

Expect **delicate JST repinning**, mains and 24 V exposure, and serious failure modes. See [`WARNING.md`](WARNING.md).

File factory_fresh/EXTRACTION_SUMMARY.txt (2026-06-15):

Factory firmware extraction  -  Artillery M1 Pro S1-SOC (RK3308BS)
Updated: 2026-06-10

=== WHAT THIS IS GOOD FOR ===

Reference only  -  NOT a magic “make Armbian boot” button:
  - Factory partition blobs (03_partitions/)
  - Decompiled device tree (05_dts/rk3308-factory.dts)
  - Boot.img layout notes (04_boot_unpacked/)
  - Repack smoke tests (06_smoke_test/)

=== WHAT WAS BROKEN (AND WHY FLASH FAILED) ===

1) v1 smoke image (SMOKE_TEST_serial_console.img)
   Rebuilt boot.img with mkbootimg + UNCOMPRESSED kernel.
   Factory boot.img uses LZ4-compressed kernel  -  U-Boot rejects v1 images.

2) pack-armbian-for-emmc.sh (OLD)
   Same mkbootimg mistake. Also used console=ttyS3 while factory DTB still
   enables fiq-debugger on UART3  -  ttyS3 and ttyFIQ0 conflict on same pins.

3) Boot cmdline vs device tree
   Factory boot.img header cmdline is EMPTY. Real bootargs live in DTB
   chosen node: console=ttyFIQ0 + fiq-debugger on serial-id 3 @ 1500000.
   Patching only boot.img to ttyS3 without changing resource.img DTB usually
   gives no serial output.

4) Rootfs UUID
   Factory cmdline uses root=PARTUUID=614e0000-0000-4b53-8000-1d28000054a9.
   Swapping rootfs.img without tune2fs -U to that UUID breaks boot.

5) unpack-boot.sh had wrong path (fixed  -  now script-relative).

=== DIRECTORIES ===

  01_update_img/       Raw .img from zip
  02_rkimagemaker/     boot.bin + firmware.img
  03_partitions/       Flashable partitions (~5 GB)  -  use as --factory
  04_boot_unpacked/    Kernel + resource.img (from unpack-boot.sh)
  05_dts/              rk3308-factory.dts + .dtb
  06_smoke_test/       Serial / repack validation images
  tools/               patch-bootimg-cmdline.sh

=== FACTORY BOOT CHAIN ===

  boot.img cmdline in header:  EMPTY (bootargs come from DTB until patched)
  Linux bootargs (in DTS):     console=ttyFIQ0 earlycon=uart8250,mmio32,0xff0d0000
  boot.img kernel:             LZ4 inside Android boot image  -  DO NOT replace with raw vmlinuz
  boot.img second slot:        Rockchip resource.img (DTB bundle)

=== SMOKE TEST ORDER (flash with RKDevTool  ->  Upgrade Firmware) ===

  1) 06_smoke_test/SMOKE_v2_repack_only/SMOKE_v2_repack_only.img
     Exact factory boot.img + repacked rest. Must behave like factory.
     If this FAILS: repack/flash/hardware  -  not console settings.

  2) 06_smoke_test/SMOKE_v2_fiq_console/SMOKE_v2_fiq_console.img
     Patched boot.img cmdline: console=ttyFIQ0 (matches factory DTB)
     Serial: UART3 @ 1500000, jumper on SERIAL

  3) 06_smoke_test/SMOKE_v2_ttyS3_console/SMOKE_v2_ttyS3_console.img
     Patched cmdline: console=ttyS3  -  may NOT work until resource.img DTB
     disables fiq-debugger. Prefer fiq_console for factory kernel.

  DO NOT flash: SMOKE_TEST_serial_console.img (v1 / broken)

=== ARMBIAN PACK (FIXED pack-armbian-for-emmc.sh) ===

  On Ubuntu/WSL:
    ./pack-armbian-for-emmc.sh \
      --armbian /path/to/Armbian-*.img \
      --factory factory_fresh/03_partitions \
      --out pack_work

  On Windows:
    .\\windows-pack-update.ps1 -PackInput pack_work\\pack_input

  Script now:
    - Keeps factory boot.img (LZ4 kernel + resource.img)
    - Patches cmdline only (default console=ttyFIQ0)
    - Replaces rootfs.img from Armbian partition
    - Sets ext4 UUID to factory PARTUUID via tune2fs

  Still uses FACTORY kernel until you build a Rockchip-format LZ4 boot.img
  with your Armbian kernel  -  that is a separate step.

=== RUN RK3308_AUDIT.SH ON THE BOARD ===

  After any flash that boots, run RK3308_AUDIT.SH on-device and compare
  device_tree/ + dmesg to factory_fresh/05_dts/.

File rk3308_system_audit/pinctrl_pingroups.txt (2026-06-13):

registered pin groups:
group: canm0-pins
pin 11 (gpio0-11)
pin 12 (gpio0-12)

group: canm1-pins
pin 54 (gpio1-22)
pin 55 (gpio1-23)

group: canm2-pins
pin 66 (gpio2-2)
pin 67 (gpio2-3)

group: emmc-clk
pin 105 (gpio3-9)

group: emmc-cmd
pin 104 (gpio3-8)

group: emmc-pwren
pin 107 (gpio3-11)

group: emmc-rstn
pin 106 (gpio3-10)

group: emmc-bus1
pin 96 (gpio3-0)

group: emmc-bus4
pin 96 (gpio3-0)
pin 97 (gpio3-1)
pin 98 (gpio3-2)
pin 99 (gpio3-3)

group: emmc-bus8
pin 96 (gpio3-0)
pin 97 (gpio3-1)
pin 98 (gpio3-2)
pin 99 (gpio3-3)
pin 100 (gpio3-4)
pin 101 (gpio3-5)
pin 102 (gpio3-6)
pin 103 (gpio3-7)

group: ext-micbias-en
pin 18 (gpio0-18)

group: flash-csn0
pin 109 (gpio3-13)

group: flash-rdy
pin 108 (gpio3-12)

group: flash-ale
pin 107 (gpio3-11)

group: flash-cle
pin 105 (gpio3-9)

group: flash-wrn
pin 104 (gpio3-8)

group: flash-rdn
pin 106 (gpio3-10)

group: flash-bus8
pin 96 (gpio3-0)
pin 97 (gpio3-1)
pin 98 (gpio3-2)
pin 99 (gpio3-3)
pin 100 (gpio3-4)
pin 101 (gpio3-5)
pin 102 (gpio3-6)
pin 103 (gpio3-7)

group: rmii-pins
pin 49 (gpio1-17)
pin 51 (gpio1-19)
pin 50 (gpio1-18)
pin 52 (gpio1-20)
pin 53 (gpio1-21)
pin 47 (gpio1-15)
pin 48 (gpio1-16)
pin 46 (gpio1-14)
pin 45 (gpio1-13)

group: mac-refclk-12ma
pin 44 (gpio1-12)

group: mac-refclk
pin 44 (gpio1-12)

group: rmiim1-pins
pin 143 (gpio4-15)
pin 133 (gpio4-5)
pin 132 (gpio4-4)
pin 130 (gpio4-2)
pin 131 (gpio4-3)
pin 128 (gpio4-0)
pin 129 (gpio4-1)
pin 142 (gpio4-14)
pin 141 (gpio4-13)

group: macm1-refclk-12ma
pin 140 (gpio4-12)

group: macm1-refclk
pin 140 (gpio4-12)

group: i2c0-xfer
pin 56 (gpio1-24)
pin 57 (gpio1-25)

group: i2c1-xfer
pin 11 (gpio0-11)
pin 12 (gpio0-12)

group: i2c2-xfer
pin 66 (gpio2-2)
pin 67 (gpio2-3)

group: i2c3m0-xfer
pin 15 (gpio0-15)
pin 16 (gpio0-16)

group: i2c3m1-xfer
pin 108 (gpio3-12)
pin 109 (gpio3-13)

group: i2c3m2-xfer
pin 65 (gpio2-1)
pin 64 (gpio2-0)

group: i2s-2ch-0-mclk
pin 140 (gpio4-12)

group: i2s-2ch-0-sclk
pin 141 (gpio4-13)

group: i2s-2ch-0-lrck
pin 142 (gpio4-14)

group: i2s-2ch-0-sdo
pin 143 (gpio4-15)

group: i2s-2ch-0-sdi
pin 144 (gpio4-16)

group: i2s-8ch-0-mclk
pin 68 (gpio2-4)

group: i2s-8ch-0-sclktx
pin 69 (gpio2-5)

group: i2s-8ch-0-sclkrx
pin 70 (gpio2-6)

group: i2s-8ch-0-lrcktx
pin 71 (gpio2-7)

group: i2s-8ch-0-lrckrx
pin 72 (gpio2-8)

group: i2s-8ch-0-sdo0
pin 73 (gpio2-9)

group: i2s-8ch-0-sdo1
pin 74 (gpio2-10)

group: i2s-8ch-0-sdo2
pin 75 (gpio2-11)

group: i2s-8ch-0-sdo3
pin 76 (gpio2-12)

group: i2s-8ch-0-sdi0
pin 77 (gpio2-13)

group: i2s-8ch-0-sdi1
pin 78 (gpio2-14)

group: i2s-8ch-0-sdi2
pin 79 (gpio2-15)

group: i2s-8ch-0-sdi3
pin 80 (gpio2-16)

group: i2s-8ch-1-m0-mclk
pin 34 (gpio1-2)

group: i2s-8ch-1-m0-sclktx
pin 35 (gpio1-3)

group: i2s-8ch-1-m0-sclkrx
pin 36 (gpio1-4)

group: i2s-8ch-1-m0-lrcktx
pin 37 (gpio1-5)

group: i2s-8ch-1-m0-lrckrx
pin 38 (gpio1-6)

group: i2s-8ch-1-m0-sdo0
pin 39 (gpio1-7)

group: i2s-8ch-1-m0-sdo1-sdi3
pin 40 (gpio1-8)

group: i2s-8ch-1-m0-sdo2-sdi2
pin 41 (gpio1-9)

group: i2s-8ch-1-m0-sdo3_sdi1
pin 42 (gpio1-10)

group: i2s-8ch-1-m0-sdi0
pin 43 (gpio1-11)

group: i2s-8ch-1-m1-mclk
pin 44 (gpio1-12)

group: i2s-8ch-1-m1-sclktx
pin 45 (gpio1-13)

group: i2s-8ch-1-m1-sclkrx
pin 46 (gpio1-14)

group: i2s-8ch-1-m1-lrcktx
pin 47 (gpio1-15)

group: i2s-8ch-1-m1-lrckrx
pin 48 (gpio1-16)

group: i2s-8ch-1-m1-sdo0
pin 49 (gpio1-17)

group: i2s-8ch-1-m1-sdo1-sdi3
pin 50 (gpio1-18)

group: i2s-8ch-1-m1-sdo2-sdi2
pin 51 (gpio1-19)

group: i2s-8ch-1-m1-sdo3_sdi1
pin 52 (gpio1-20)

group: i2s-8ch-1-m1-sdi0
pin 53 (gpio1-21)

group: lcdc-ctl
pin 32 (gpio1-0)
pin 33 (gpio1-1)
pin 34 (gpio1-2)
pin 35 (gpio1-3)
pin 36 (gpio1-4)
pin 37 (gpio1-5)
pin 38 (gpio1-6)
pin 39 (gpio1-7)
pin 40 (gpio1-8)
pin 41 (gpio1-9)
pin 42 (gpio1-10)
pin 43 (gpio1-11)
pin 44 (gpio1-12)
pin 45 (gpio1-13)
pin 46 (gpio1-14)
pin 47 (gpio1-15)
pin 48 (gpio1-16)
pin 49 (gpio1-17)
pin 50 (gpio1-18)
pin 51 (gpio1-19)
pin 52 (gpio1-20)
pin 53 (gpio1-21)

group: lcdc-rgb888-m0
pin 54 (gpio1-22)
pin 55 (gpio1-23)
pin 73 (gpio2-9)
pin 74 (gpio2-10)
pin 79 (gpio2-15)
pin 80 (gpio2-16)

group: lcdc-rgb888-m1
pin 102 (gpio3-6)
pin 103 (gpio3-7)
pin 104 (gpio3-8)
pin 105 (gpio3-9)
pin 106 (gpio3-10)
pin 107 (gpio3-11)

group: owirem0-pins
pin 11 (gpio0-11)

group: owirem1-pins
pin 54 (gpio1-22)

group: owirem2-pins
pin 66 (gpio2-2)

group: pdm-m0-clk
pin 36 (gpio1-4)

group: pdm-m0-sdi0
pin 43 (gpio1-11)

group: pdm-m0-sdi1
pin 42 (gpio1-10)

group: pdm-m0-sdi2
pin 41 (gpio1-9)

group: pdm-m0-sdi3
pin 40 (gpio1-8)

group: pdm-m1-clk
pin 46 (gpio1-14)

group: pdm-m1-sdi0
pin 53 (gpio1-21)

group: pdm-m1-sdi1
pin 52 (gpio1-20)

group: pdm-m1-sdi2
pin 51 (gpio1-19)

group: pdm-m1-sdi3
pin 50 (gpio1-18)

group: pdm-m2-clkm
pin 68 (gpio2-4)

group: pdm-m2-clk
pin 70 (gpio2-6)

group: pdm-m2-sdi0
pin 77 (gpio2-13)

group: pdm-m2-sdi1
pin 78 (gpio2-14)

group: pdm-m2-sdi2
pin 79 (gpio2-15)

group: pdm-m2-sdi3
pin 80 (gpio2-16)

group: pwm0-pin
pin 13 (gpio0-13)

group: pwm0-pin-pull-down
pin 13 (gpio0-13)

group: pwm1-pin
pin 14 (gpio0-14)

group: pwm1-pin-pull-down
pin 14 (gpio0-14)

group: pwm2-pin
pin 15 (gpio0-15)

group: pwm2-pin-pull-down
pin 15 (gpio0-15)

group: pwm3-pin
pin 16 (gpio0-16)

group: pwm3-pin-pull-down
pin 16 (gpio0-16)

group: pwm4-pin
pin 1 (gpio0-1)

group: pwm4-pin-pull-down
pin 1 (gpio0-1)

group: pwm5-pin
pin 17 (gpio0-17)

group: pwm5-pin-pull-down
pin 17 (gpio0-17)

group: pwm6-pin
pin 18 (gpio0-18)

group: pwm6-pin-pull-down
pin 18 (gpio0-18)

group: pwm7-pin
pin 72 (gpio2-8)

group: pwm7-pin-pull-down
pin 72 (gpio2-8)

group: pwm8-pin
pin 74 (gpio2-10)

group: pwm8-pin-pull-down
pin 74 (gpio2-10)

group: pwm9-pin
pin 75 (gpio2-11)

group: pwm9-pin-pull-down
pin 75 (gpio2-11)

group: pwm10-pin
pin 76 (gpio2-12)

group: pwm10-pin-pull-down
pin 76 (gpio2-12)

group: pwm11-pin
pin 80 (gpio2-16)

group: pwm11-pin-pull-down
pin 80 (gpio2-16)

group: rtc-32k
pin 19 (gpio0-19)

group: sdmmc-clk
pin 157 (gpio4-29)

group: sdmmc-cmd
pin 156 (gpio4-28)

group: sdmmc-det
pin 3 (gpio0-3)

group: sdmmc-pwren
pin 158 (gpio4-30)

group: sdmmc-bus1
pin 152 (gpio4-24)

group: sdmmc-bus4
pin 152 (gpio4-24)
pin 153 (gpio4-25)
pin 154 (gpio4-26)
pin 155 (gpio4-27)

group: sdmmc-gpio
pin 152 (gpio4-24)
pin 153 (gpio4-25)
pin 154 (gpio4-26)
pin 155 (gpio4-27)
pin 156 (gpio4-28)
pin 157 (gpio4-29)
pin 158 (gpio4-30)

group: sdio-clk
pin 133 (gpio4-5)

group: sdio-cmd
pin 132 (gpio4-4)

group: sdio-pwren
pin 2 (gpio0-2)

group: sdio-wrpt
pin 1 (gpio0-1)

group: sdio-intn
pin 0 (gpio0-0)

group: sdio-bus1
pin 128 (gpio4-0)

group: sdio-bus4
pin 128 (gpio4-0)
pin 129 (gpio4-1)
pin 130 (gpio4-2)
pin 131 (gpio4-3)

group: sdio-gpio
pin 128 (gpio4-0)
pin 129 (gpio4-1)
pin 130 (gpio4-2)
pin 131 (gpio4-3)
pin 132 (gpio4-4)
pin 133 (gpio4-5)

group: spdif-in
pin 18 (gpio0-18)

group: spdif-out
pin 17 (gpio0-17)

group: spi0-clk
pin 66 (gpio2-2)

group: spi0-csn0
pin 67 (gpio2-3)

group: spi0-miso
pin 64 (gpio2-0)

group: spi0-mosi
pin 65 (gpio2-1)

group: spi0-clk-hs
pin 66 (gpio2-2)

group: spi0-miso-hs
pin 64 (gpio2-0)

group: spi0-mosi-hs
pin 65 (gpio2-1)

group: spi1-clk
pin 107 (gpio3-11)

group: spi1-csn0
pin 109 (gpio3-13)

group: spi1-miso
pin 106 (gpio3-10)

group: spi1-mosi
pin 108 (gpio3-12)

group: spi1-clk-hs
pin 107 (gpio3-11)

group: spi1-miso-hs
pin 106 (gpio3-10)

group: spi1-mosi-hs
pin 108 (gpio3-12)

group: spi1m1-miso
pin 68 (gpio2-4)

group: spi1m1-mosi
pin 69 (gpio2-5)

group: spi1m1-clk
pin 71 (gpio2-7)

group: spi1m1-csn0
pin 73 (gpio2-9)

group: spi1m1-miso-hs
pin 68 (gpio2-4)

group: spi1m1-mosi-hs
pin 69 (gpio2-5)

group: spi1m1-clk-hs
pin 71 (gpio2-7)

group: spi1m1-csn0-hs
pin 73 (gpio2-9)

group: spi2-clk
pin 56 (gpio1-24)

group: spi2-csn0
pin 57 (gpio1-25)

group: spi2-miso
pin 54 (gpio1-22)

group: spi2-mosi
pin 55 (gpio1-23)

group: spi2-clk-hs
pin 56 (gpio1-24)

group: spi2-miso-hs
pin 54 (gpio1-22)

group: spi2-mosi-hs
pin 55 (gpio1-23)

group: tsadc-otp-pin
pin 10 (gpio0-10)

group: tsadc-otp-out
pin 10 (gpio0-10)

group: uart0-xfer
pin 65 (gpio2-1)
pin 64 (gpio2-0)

group: uart0-cts
pin 66 (gpio2-2)

group: uart0-rts
pin 67 (gpio2-3)

group: uart0-rts-pin
pin 67 (gpio2-3)

group: uart1-xfer
pin 57 (gpio1-25)
pin 56 (gpio1-24)

group: uart1-cts
pin 54 (gpio1-22)

group: uart1-rts
pin 55 (gpio1-23)

group: uart2m0-xfer
pin 55 (gpio1-23)
pin 54 (gpio1-22)

group: uart2m1-xfer
pin 155 (gpio4-27)
pin 154 (gpio4-26)

group: uart3-xfer
pin 109 (gpio3-13)
pin 108 (gpio3-12)

group: uart3m1-xfer
pin 18 (gpio0-18)
pin 17 (gpio0-17)

group: uart4-xfer
pin 137 (gpio4-9)
pin 136 (gpio4-8)

group: uart4-cts
pin 134 (gpio4-6)

group: uart4-rts
pin 135 (gpio4-7)

group: uart4-rts-pin
pin 135 (gpio4-7)

group: usb-drv
pin 21 (gpio0-21)

group: wifi-enable-h
pin 2 (gpio0-2)

group: uart0-gpios
pin 67 (gpio2-3)

group: wifi-wake-host
pin 0 (gpio0-0)

group: green-led-gpio
pin 6 (gpio0-6)

group: heartbeat-led-gpio
pin 5 (gpio0-5)

group: pinctrl_spi1_cs0
pin 77 (gpio2-13)

group: pmic-int-l
pin 6 (gpio0-6)

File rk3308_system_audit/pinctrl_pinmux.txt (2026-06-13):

function: pcfg-pull-up, groups = [ ]
function: pcfg-pull-down, groups = [ ]
function: pcfg-pull-none, groups = [ ]
function: pcfg-pull-none-2ma, groups = [ ]
function: pcfg-pull-up-2ma, groups = [ ]
function: pcfg-pull-up-4ma, groups = [ ]
function: pcfg-pull-none-4ma, groups = [ ]
function: pcfg-pull-down-4ma, groups = [ ]
function: pcfg-pull-none-8ma, groups = [ ]
function: pcfg-pull-up-8ma, groups = [ ]
function: pcfg-pull-none-12ma, groups = [ ]
function: pcfg-pull-up-12ma, groups = [ ]
function: pcfg-pull-none-smt, groups = [ ]
function: pcfg-output-high, groups = [ ]
function: pcfg-output-low, groups = [ ]
function: pcfg-input-high, groups = [ ]
function: pcfg-input, groups = [ ]
function: can-m0, groups = [ canm0-pins ]
function: can-m1, groups = [ canm1-pins ]
function: can-m2, groups = [ canm2-pins ]
function: emmc, groups = [ emmc-clk emmc-cmd emmc-pwren emmc-rstn emmc-bus1 emmc-bus4 emmc-bus8 ]
function: ext_micbias, groups = [ ext-micbias-en ]
function: flash, groups = [ flash-csn0 flash-rdy flash-ale flash-cle flash-wrn flash-rdn flash-bus8 ]
function: gmac, groups = [ rmii-pins mac-refclk-12ma mac-refclk ]
function: gmac-m1, groups = [ rmiim1-pins macm1-refclk-12ma macm1-refclk ]
function: i2c0, groups = [ i2c0-xfer ]
function: i2c1, groups = [ i2c1-xfer ]
function: i2c2, groups = [ i2c2-xfer ]
function: i2c3-m0, groups = [ i2c3m0-xfer ]
function: i2c3-m1, groups = [ i2c3m1-xfer ]
function: i2c3-m2, groups = [ i2c3m2-xfer ]
function: i2s_2ch_0, groups = [ i2s-2ch-0-mclk i2s-2ch-0-sclk i2s-2ch-0-lrck i2s-2ch-0-sdo i2s-2ch-0-sdi ]
function: i2s_8ch_0, groups = [ i2s-8ch-0-mclk i2s-8ch-0-sclktx i2s-8ch-0-sclkrx i2s-8ch-0-lrcktx i2s-8ch-0-lrckrx i2s-8ch-0-sdo0 i2s-8ch-0-sdo1 i2s-8ch-0-sdo2 i2s-8ch-0-sdo3 i2s-8ch-0-sdi0 i2s-8ch-0-sdi1 i2s-8ch-0-sdi2 i2s-8ch-0-sdi3 ]
function: i2s_8ch_1_m0, groups = [ i2s-8ch-1-m0-mclk i2s-8ch-1-m0-sclktx i2s-8ch-1-m0-sclkrx i2s-8ch-1-m0-lrcktx i2s-8ch-1-m0-lrckrx i2s-8ch-1-m0-sdo0 i2s-8ch-1-m0-sdo1-sdi3 i2s-8ch-1-m0-sdo2-sdi2 i2s-8ch-1-m0-sdo3_sdi1 i2s-8ch-1-m0-sdi0 ]
function: i2s_8ch_1_m1, groups = [ i2s-8ch-1-m1-mclk i2s-8ch-1-m1-sclktx i2s-8ch-1-m1-sclkrx i2s-8ch-1-m1-lrcktx i2s-8ch-1-m1-lrckrx i2s-8ch-1-m1-sdo0 i2s-8ch-1-m1-sdo1-sdi3 i2s-8ch-1-m1-sdo2-sdi2 i2s-8ch-1-m1-sdo3_sdi1 i2s-8ch-1-m1-sdi0 ]
function: lcdc, groups = [ lcdc-ctl lcdc-rgb888-m0 lcdc-rgb888-m1 ]
function: owire-m0, groups = [ owirem0-pins ]
function: owire-m1, groups = [ owirem1-pins ]
function: owire-m2, groups = [ owirem2-pins ]
function: pdm_m0, groups = [ pdm-m0-clk pdm-m0-sdi0 pdm-m0-sdi1 pdm-m0-sdi2 pdm-m0-sdi3 ]
function: pdm_m1, groups = [ pdm-m1-clk pdm-m1-sdi0 pdm-m1-sdi1 pdm-m1-sdi2 pdm-m1-sdi3 ]
function: pdm_m2, groups = [ pdm-m2-clkm pdm-m2-clk pdm-m2-sdi0 pdm-m2-sdi1 pdm-m2-sdi2 pdm-m2-sdi3 ]
function: pwm0, groups = [ pwm0-pin pwm0-pin-pull-down ]
function: pwm1, groups = [ pwm1-pin pwm1-pin-pull-down ]
function: pwm2, groups = [ pwm2-pin pwm2-pin-pull-down ]
function: pwm3, groups = [ pwm3-pin pwm3-pin-pull-down ]
function: pwm4, groups = [ pwm4-pin pwm4-pin-pull-down ]
function: pwm5, groups = [ pwm5-pin pwm5-pin-pull-down ]
function: pwm6, groups = [ pwm6-pin pwm6-pin-pull-down ]
function: pwm7, groups = [ pwm7-pin pwm7-pin-pull-down ]
function: pwm8, groups = [ pwm8-pin pwm8-pin-pull-down ]
function: pwm9, groups = [ pwm9-pin pwm9-pin-pull-down ]
function: pwm10, groups = [ pwm10-pin pwm10-pin-pull-down ]
function: pwm11, groups = [ pwm11-pin pwm11-pin-pull-down ]
function: rtc, groups = [ rtc-32k ]
function: sdmmc, groups = [ sdmmc-clk sdmmc-cmd sdmmc-det sdmmc-pwren sdmmc-bus1 sdmmc-bus4 sdmmc-gpio ]
function: sdio, groups = [ sdio-clk sdio-cmd sdio-pwren sdio-wrpt sdio-intn sdio-bus1 sdio-bus4 sdio-gpio ]
function: spdif_in, groups = [ spdif-in ]
function: spdif_out, groups = [ spdif-out ]
function: spi0, groups = [ spi0-clk spi0-csn0 spi0-miso spi0-mosi spi0-clk-hs spi0-miso-hs spi0-mosi-hs ]
function: spi1, groups = [ spi1-clk spi1-csn0 spi1-miso spi1-mosi spi1-clk-hs spi1-miso-hs spi1-mosi-hs ]
function: spi1-m1, groups = [ spi1m1-miso spi1m1-mosi spi1m1-clk spi1m1-csn0 spi1m1-miso-hs spi1m1-mosi-hs spi1m1-clk-hs spi1m1-csn0-hs ]
function: spi2, groups = [ spi2-clk spi2-csn0 spi2-miso spi2-mosi spi2-clk-hs spi2-miso-hs spi2-mosi-hs ]
function: tsadc, groups = [ tsadc-otp-pin tsadc-otp-out ]
function: uart0, groups = [ uart0-xfer uart0-cts uart0-rts uart0-rts-pin ]
function: uart1, groups = [ uart1-xfer uart1-cts uart1-rts ]
function: uart2-m0, groups = [ uart2m0-xfer ]
function: uart2-m1, groups = [ uart2m1-xfer ]
function: uart3, groups = [ uart3-xfer ]
function: uart3-m1, groups = [ uart3m1-xfer ]
function: uart4, groups = [ uart4-xfer uart4-cts uart4-rts uart4-rts-pin ]
function: pcfg-pull-none-0-4ma, groups = [ ]
function: pcfg-pull-none-0-4ma-smt, groups = [ ]
function: pcfg-pull-up-0-4ma, groups = [ ]
function: pcfg-pull-down-0-4ma, groups = [ ]
function: pcfg-pull-none-0-6ma, groups = [ ]
function: pcfg-pull-up-0-6ma, groups = [ ]
function: pcfg-pull-down-0-6ma, groups = [ ]
function: pcfg-pull-none-4-6ma, groups = [ ]
function: pcfg-pull-up-4-6ma, groups = [ ]
function: pcfg-pull-down-4-6ma, groups = [ ]
function: pcfg-pull-none-8-6ma, groups = [ ]
function: pcfg-pull-up-8-6ma, groups = [ ]
function: pcfg-pull-down-8-6ma, groups = [ ]
function: pcfg-pull-none-8-4ma, groups = [ ]
function: pcfg-pull-up-8-4ma, groups = [ ]
function: pcfg-pull-down-8-4ma, groups = [ ]
function: pcfg-pull-none-12-4ma, groups = [ ]
function: pcfg-pull-up-12-4ma, groups = [ ]
function: pcfg-pull-down-12-4ma, groups = [ ]
function: pcfg-pull-none-12-6ma, groups = [ ]
function: pcfg-pull-up-12-6ma, groups = [ ]
function: pcfg-pull-down-12-6ma, groups = [ ]
function: usb, groups = [ usb-drv ]
function: sdio-pwrseq, groups = [ wifi-enable-h ]
function: wireless-bluetooth, groups = [ uart0-gpios ]
function: wireless-wlan, groups = [ wifi-wake-host ]
function: leds, groups = [ green-led-gpio heartbeat-led-gpio ]
function: spi1_cs0, groups = [ pinctrl_spi1_cs0 ]
function: pmic, groups = [ pmic-int-l ]

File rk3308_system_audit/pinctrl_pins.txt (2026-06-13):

registered pins: 160
pin 0 (gpio0-0) 0:gpio0 
pin 1 (gpio0-1) 1:gpio0 
pin 2 (gpio0-2) 2:gpio0 
pin 3 (gpio0-3) 3:gpio0 
pin 4 (gpio0-4) 4:gpio0 
pin 5 (gpio0-5) 5:gpio0 
pin 6 (gpio0-6) 6:gpio0 
pin 7 (gpio0-7) 7:gpio0 
pin 8 (gpio0-8) 8:gpio0 
pin 9 (gpio0-9) 9:gpio0 
pin 10 (gpio0-10) 10:gpio0 
pin 11 (gpio0-11) 11:gpio0 
pin 12 (gpio0-12) 12:gpio0 
pin 13 (gpio0-13) 13:gpio0 
pin 14 (gpio0-14) 14:gpio0 
pin 15 (gpio0-15) 15:gpio0 
pin 16 (gpio0-16) 16:gpio0 
pin 17 (gpio0-17) 17:gpio0 
pin 18 (gpio0-18) 18:gpio0 
pin 19 (gpio0-19) 19:gpio0 
pin 20 (gpio0-20) 20:gpio0 
pin 21 (gpio0-21) 21:gpio0 
pin 22 (gpio0-22) 22:gpio0 
pin 23 (gpio0-23) 23:gpio0 
pin 24 (gpio0-24) 24:gpio0 
pin 25 (gpio0-25) 25:gpio0 
pin 26 (gpio0-26) 26:gpio0 
pin 27 (gpio0-27) 27:gpio0 
pin 28 (gpio0-28) 28:gpio0 
pin 29 (gpio0-29) 29:gpio0 
pin 30 (gpio0-30) 30:gpio0 
pin 31 (gpio0-31) 31:gpio0 
pin 32 (gpio1-0) 0:gpio1 
pin 33 (gpio1-1) 1:gpio1 
pin 34 (gpio1-2) 2:gpio1 
pin 35 (gpio1-3) 3:gpio1 
pin 36 (gpio1-4) 4:gpio1 
pin 37 (gpio1-5) 5:gpio1 
pin 38 (gpio1-6) 6:gpio1 
pin 39 (gpio1-7) 7:gpio1 
pin 40 (gpio1-8) 8:gpio1 
pin 41 (gpio1-9) 9:gpio1 
pin 42 (gpio1-10) 10:gpio1 
pin 43 (gpio1-11) 11:gpio1 
pin 44 (gpio1-12) 12:gpio1 
pin 45 (gpio1-13) 13:gpio1 
pin 46 (gpio1-14) 14:gpio1 
pin 47 (gpio1-15) 15:gpio1 
pin 48 (gpio1-16) 16:gpio1 
pin 49 (gpio1-17) 17:gpio1 
pin 50 (gpio1-18) 18:gpio1 
pin 51 (gpio1-19) 19:gpio1 
pin 52 (gpio1-20) 20:gpio1 
pin 53 (gpio1-21) 21:gpio1 
pin 54 (gpio1-22) 22:gpio1 
pin 55 (gpio1-23) 23:gpio1 
pin 56 (gpio1-24) 24:gpio1 
pin 57 (gpio1-25) 25:gpio1 
pin 58 (gpio1-26) 26:gpio1 
pin 59 (gpio1-27) 27:gpio1 
pin 60 (gpio1-28) 28:gpio1 
pin 61 (gpio1-29) 29:gpio1 
pin 62 (gpio1-30) 30:gpio1 
pin 63 (gpio1-31) 31:gpio1 
pin 64 (gpio2-0) 0:gpio2 
pin 65 (gpio2-1) 1:gpio2 
pin 66 (gpio2-2) 2:gpio2 
pin 67 (gpio2-3) 3:gpio2 
pin 68 (gpio2-4) 4:gpio2 
pin 69 (gpio2-5) 5:gpio2 
pin 70 (gpio2-6) 6:gpio2 
pin 71 (gpio2-7) 7:gpio2 
pin 72 (gpio2-8) 8:gpio2 
pin 73 (gpio2-9) 9:gpio2 
pin 74 (gpio2-10) 10:gpio2 
pin 75 (gpio2-11) 11:gpio2 
pin 76 (gpio2-12) 12:gpio2 
pin 77 (gpio2-13) 13:gpio2 
pin 78 (gpio2-14) 14:gpio2 
pin 79 (gpio2-15) 15:gpio2 
pin 80 (gpio2-16) 16:gpio2 
pin 81 (gpio2-17) 17:gpio2 
pin 82 (gpio2-18) 18:gpio2 
pin 83 (gpio2-19) 19:gpio2 
pin 84 (gpio2-20) 20:gpio2 
pin 85 (gpio2-21) 21:gpio2 
pin 86 (gpio2-22) 22:gpio2 
pin 87 (gpio2-23) 23:gpio2 
pin 88 (gpio2-24) 24:gpio2 
pin 89 (gpio2-25) 25:gpio2 
pin 90 (gpio2-26) 26:gpio2 
pin 91 (gpio2-27) 27:gpio2 
pin 92 (gpio2-28) 28:gpio2 
pin 93 (gpio2-29) 29:gpio2 
pin 94 (gpio2-30) 30:gpio2 
pin 95 (gpio2-31) 31:gpio2 
pin 96 (gpio3-0) 0:gpio3 
pin 97 (gpio3-1) 1:gpio3 
pin 98 (gpio3-2) 2:gpio3 
pin 99 (gpio3-3) 3:gpio3 
pin 100 (gpio3-4) 4:gpio3 
pin 101 (gpio3-5) 5:gpio3 
pin 102 (gpio3-6) 6:gpio3 
pin 103 (gpio3-7) 7:gpio3 
pin 104 (gpio3-8) 8:gpio3 
pin 105 (gpio3-9) 9:gpio3 
pin 106 (gpio3-10) 10:gpio3 
pin 107 (gpio3-11) 11:gpio3 
pin 108 (gpio3-12) 12:gpio3 
pin 109 (gpio3-13) 13:gpio3 
pin 110 (gpio3-14) 14:gpio3 
pin 111 (gpio3-15) 15:gpio3 
pin 112 (gpio3-16) 16:gpio3 
pin 113 (gpio3-17) 17:gpio3 
pin 114 (gpio3-18) 18:gpio3 
pin 115 (gpio3-19) 19:gpio3 
pin 116 (gpio3-20) 20:gpio3 
pin 117 (gpio3-21) 21:gpio3 
pin 118 (gpio3-22) 22:gpio3 
pin 119 (gpio3-23) 23:gpio3 
pin 120 (gpio3-24) 24:gpio3 
pin 121 (gpio3-25) 25:gpio3 
pin 122 (gpio3-26) 26:gpio3 
pin 123 (gpio3-27) 27:gpio3 
pin 124 (gpio3-28) 28:gpio3 
pin 125 (gpio3-29) 29:gpio3 
pin 126 (gpio3-30) 30:gpio3 
pin 127 (gpio3-31) 31:gpio3 
pin 128 (gpio4-0) 0:gpio4 
pin 129 (gpio4-1) 1:gpio4 
pin 130 (gpio4-2) 2:gpio4 
pin 131 (gpio4-3) 3:gpio4 
pin 132 (gpio4-4) 4:gpio4 
pin 133 (gpio4-5) 5:gpio4 
pin 134 (gpio4-6) 6:gpio4 
pin 135 (gpio4-7) 7:gpio4 
pin 136 (gpio4-8) 8:gpio4 
pin 137 (gpio4-9) 9:gpio4 
pin 138 (gpio4-10) 10:gpio4 
pin 139 (gpio4-11) 11:gpio4 
pin 140 (gpio4-12) 12:gpio4 
pin 141 (gpio4-13) 13:gpio4 
pin 142 (gpio4-14) 14:gpio4 
pin 143 (gpio4-15) 15:gpio4 
pin 144 (gpio4-16) 16:gpio4 
pin 145 (gpio4-17) 17:gpio4 
pin 146 (gpio4-18) 18:gpio4 
pin 147 (gpio4-19) 19:gpio4 
pin 148 (gpio4-20) 20:gpio4 
pin 149 (gpio4-21) 21:gpio4 
pin 150 (gpio4-22) 22:gpio4 
pin 151 (gpio4-23) 23:gpio4 
pin 152 (gpio4-24) 24:gpio4 
pin 153 (gpio4-25) 25:gpio4 
pin 154 (gpio4-26) 26:gpio4 
pin 155 (gpio4-27) 27:gpio4 
pin 156 (gpio4-28) 28:gpio4 
pin 157 (gpio4-29) 29:gpio4 
pin 158 (gpio4-30) 30:gpio4 
pin 159 (gpio4-31) 31:gpio4

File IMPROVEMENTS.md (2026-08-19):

# Build System Improvements Summary

## What Changed

The new build system addresses your concerns:

### ✅ Problem 1: "Why create Armbian tools in the folder if we don't use them?"

**Old way:**
- Downloaded fresh Armbian every build
- Each build took 45+ minutes (full toolchain, kernel, rootfs)
- No reuse of cached files

**New way:**
- Creates **persistent /home/xateesix/scratch/Projects/rk3308bs-workspace/M1-SOC-Armbian-Build on your local workspace**
- Caches all toolchains, sources, downloads
- Subsequent builds take only **20-30 minutes** (just kernel recompile)
- Automatic git pull keeps packages fresh

### ✅ Problem 2: "How to setup WiFi?"

**Old way:**
- Manual SSH after boot, run commands
- No pre-configuration

**New way:**
- Credentials baked into image via overlay system
- WiFi auto-connects on first boot
- Can be changed later if needed:
  ```bash
  ssh root@board
  nano /etc/netplan/01-rk3308bs-wlan0.yaml
  netplan apply
  ```

### ✅ Problem 3: "Force a root password on first run?"

**Old way:**
- Default Armbian behavior: prompt on first login
- Password change is mandatory but slow

**New way:**
- Password pre-configured during build
- No interactive prompt
- Direct login: `ssh root@BOARD_IP` with your password
- SHA512 hashed in rootfs

---

## New Files

### `config.env`
Single source-of-truth for your setup. Edit once, reuse forever:
```bash
BUILD_SERVER_HOST="ubuntu-server"
BUILD_SERVER_USER="xateesix"
BUILD_SERVER_PATH="/home/xateesix/scratch/Projects/rk3308bs-workspace/M1-SOC-Armbian-Build"

WIFI_SSID="OurIOT"
WIFI_PASSWORD="mNhTYTeh#p3LnRw^Ln*N3VwiD"
ROOT_PASSWORD="ztfalxtspv"
```

### `build-enhanced.sh`
Main build orchestrator. Handles:
- Remote SSH build on Ubuntu server
- Persistent Armbian repo management
- WiFi pre-config overlay creation
- Root password script generation
- Automatic image download
- Build time: **25-35 minutes** (vs 45-90 with old script)

### `setup-validate.sh`
Pre-build validation. Checks:
- All files present (DTS, patch, config)
- SSH connectivity working
- Build server disk space
- Permissions set correctly

### `README.md`
Complete documentation:
- Quick start (5 steps)
- Configuration details
- Troubleshooting guide
- Hardware specs

### `GITHUB_SETUP.md`
Optional GitHub integration for:
- Cross-device sync
- Collaboration with team members
- Archive of builds

---

## Workflow Comparison

### Old Workflow
```
┌─ Windows Machine ──────┐
│ Run build.sh           │  
└────────┬────────────────┘
         │ SCP files
         ▼
┌─ Ubuntu Server ────────┐
│ Clone Armbian fresh    │  ⏱️ 10 mins
│ Copy files             │
│ Run Armbian build      │  ⏱️ 45-90 mins
│ Output to folder       │
└────────┬────────────────┘
         │ SCP image back
         ▼
Windows: Image ready
```

**Total time: 1-2 hours**

---

### New Workflow
```
┌─ Windows Machine ──────────────┐
│ setup-validate.sh              │  Checks everything
└────────┬────────────────────────┘
         │
┌────────▼──────────────────────┐
│ build-enhanced.sh              │
│ (Manage persistent repo)       │
│ (Apply WiFi/password overlays) │
└────────┬──────────────────────┘
         │ SSH + SCP files
         ▼
┌─ Ubuntu Server (Fast Reuse) ──┐
│ /home/xateesix/scratch/Projects/rk3308bs-workspace/M1-SOC-Armbian-Build (persistent) │
│ ├─ Toolchains (cached)        │
│ ├─ Kernel source (cached)     │
│ └─ Build environment          │
│                               │
│ Only recompile kernel + DTB   │  ⏱️ 25 mins
│ Download image back           │
└────────┬──────────────────────┘
         ▼
Windows: Image ready
   + WiFi pre-configured
   + Root password set
```

**Total time: 5-30 minutes** (first build 45min, subsequent builds 25min)

---

## Usage

### First Build (Setup)
```bash
cd Armbian

# Edit config with your server, WiFi, password
nano config.env

# Validate everything works
chmod +x setup-validate.sh
./setup-validate.sh

# Build (this creates persistent repo on server)
chmod +x build-enhanced.sh
./build-enhanced.sh
```

Time: ~45 minutes (one-time, large downloads)

### Subsequent Builds (After DTS Changes)
```bash
cd Armbian

# Edit your rk3308bs-evb-amic-v11.dts
nano rk3308bs-evb-amic-v11.dts

# Quick rebuild (reuses cached toolchain)
./build-enhanced.sh kernel
```

Time: ~25 minutes

### Make WiFi Changes
Edit the overlay (or on device after boot):

**On device:**
```bash
ssh root@BOARD_IP
nano /etc/netplan/01-rk3308bs-wlan0.yaml
netplan apply
```

**In image (before flash):**
1. Edit `config.env` with new WiFi
2. Run `./build-enhanced.sh` (rebuilds with new SSID/password)

---

## Key Benefits

| Aspect | Before | After |
|---|---|---|
| Build time | 45-90 min | 25-30 min |
| Reuse across builds | ❌ No | ✅ Yes |
| WiFi pre-configured | ❌ Manual | ✅ Automatic |
| Root password | ⏱️ Interactive prompt | ✅ Pre-set |
| Config in one place | ❌ No | ✅ Yes (config.env) |
| GitHub sync | ❌ No | ✅ Optional |
| Validation before build | ❌ No | ✅ Yes (setup-validate.sh) |

---

## Advanced: Local Builds

If you want to build locally on Ubuntu (without remote SSH):

```bash
# Install Armbian build dependencies
cd ~
git clone --depth=1 https://github.com/armbian/build armbian-build
cd armbian-build

# Then from Armbian folder:
ARMBIAN_PATH=$HOME/armbian-build ./build-enhanced.sh
```

Or edit `config.env`:
```bash
BUILD_SERVER=local        # Use local Armbian instead of SSH
ARMBIAN_PATH=$HOME/armbian-build
```

---

## Troubleshooting Changes

### Old: Image has no WiFi
```bash
# Manually SSH after boot
ssh root@BOARD_IP
wpa_cli add_network
wpa_cli set_network 0 ssid '"WiFi"'
# ... many manual steps
```

### New: WiFi works immediately
- Boots → WiFi connects automatically
- Check: `ssh root@BOARD_IP "iwconfig wlan0"`

---

## Next Steps

1. **Now**: Run `./setup-validate.sh` to verify everything
2. **First build**: `./build-enhanced.sh` (creates persistent repo)
3. **Later builds**: `./build-enhanced.sh kernel` (fast, 25 min)
4. **Modify**: Edit `config.env` or `rk3308bs-evb-amic-v11.dts`, then rebuild
5. **Optional**: Follow `GITHUB_SETUP.md` for GitHub sync

---

## Questions?

See:
- `README.md` - Complete user guide
- `GITHUB_SETUP.md` - GitHub collaboration setup
- `config.env` - Inline configuration docs
- `build-enhanced.sh` - Inline script comments

Build status visible in log:
```bash
tail -f build-remote.log
```

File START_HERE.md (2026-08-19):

# 📖 Armbian Build System  -  Complete Guide

## 🎯 What You Get

A **complete, professional Armbian build system** for your RK3308BS EVB that:
- ✅ Pre-configures WiFi (no manual setup needed)
- ✅ Sets root password automatically (no interactive prompt)
- ✅ Caches build files on server (2nd builds: 25 min vs 1st: 45 min)
- ✅ One config file for everything (`config.env`)
- ✅ Validates setup before building
- ✅ Handles all complexity automatically

---

## 📂 Files in This Folder

| File | Purpose |
|---|---|
| **RESUME_HERE.md** ⭐ | **Session pickup**  -  where we left off, v45 pipeline, troubleshooting |
| **QUICKSTART.md** ⭐ | **First build**  -  3-step Armbian compile guide |
| **config.env** | Configuration (WiFi, password, server) |
| **build-enhanced.sh** | Main build script (automatic WiFi + password setup) |
| **setup-validate.sh** | Pre-build checker (before first build) |
| **README.md** | Complete documentation & troubleshooting |
| **IMPROVEMENTS.md** | What changed vs old build system |
| **GITHUB_SETUP.md** | Optional GitHub sync for collaboration |
| **rk3308bs-evb.conf** | Board metadata for Armbian |
| **rk3308bs-evb-amic-v11.dts** | Hardware device tree |
| **0001-*.patch** | Kernel patch to add DTB to build |
| **build.sh** | Old build script (keep for reference) |

---

## ⚡ Quick Start (5 Minutes)

### 1️⃣ Configure
```bash
cd Armbian
nano config.env

# Edit:
# - BUILD_SERVER_HOST = your Ubuntu machine name
# - WIFI_SSID / WIFI_PASSWORD = your network
# - ROOT_PASSWORD = your choice
```

### 2️⃣ Validate  
```bash
chmod +x setup-validate.sh
./setup-validate.sh
```

You should see: `✅ All Checks Passed!`

### 3️⃣ Build
```bash
chmod +x build-enhanced.sh
./build-enhanced.sh
```

Wait ~30 minutes. Image downloads when done.

### 4️⃣ Flash
Use **balenaEtcher** or Linux `dd` command (see QUICKSTART.md)

### 5️⃣ Boot
- Insert microSD into RK3308BS
- Connect power + USB
- WiFi auto-connects
- SSH: `ssh root@BOARD_IP` (password from config.env)

---

## 🔧 What's Different From Old System?

### Problem  ->  Solution

| Problem | Old Way | New Way |
|---|---|---|
| **Long builds** | 45-90 min every time | 1st: 45 min, 2nd+: 25 min (caching) |
| **No WiFi config** | Manual SSH setup | Pre-configured, auto-connects |
| **No root password** | Interactive prompt | Pre-set, direct login |
| **Config scattered** | Multiple files | Single `config.env` |
| **Can't validate** | Hope it works | `setup-validate.sh` checks everything |

---

## 📊 Build Timeline

```
First Build:
  1. setup-validate.sh ........... 2 min (checks everything)
  2. build-enhanced.sh ........... 45 min (downloads toolchains+builds)
  3. Download image locally ....... 5 min
  ────────────────────────────────────
  Total: ~50 minutes

Later Builds (after DTS edits):
  1. ./build-enhanced.sh kernel .. 25 min (reuses cached toolchain)
  2. Download image .............. 5 min
  ────────────────────────────────────
  Total: ~30 minutes

Manual WiFi/password changes:
  (No rebuild needed - edit on device after boot)
```

---

## 🚨 Troubleshooting

**Q: SSH connection fails**
- Check Ubuntu server is running
- Verify hostname in config.env
- Run: `ssh xateesix@ubuntu-server` manually

**Q: Build takes forever**
- First build downloads ~2GB of toolchains (normal)
- Later builds much faster (cached)
- Check: `ssh xateesix@ubuntu-server tail -f /home/xateesix/scratch/Projects/rk3308bs-workspace/M1-SOC-Armbian-Build/output/logs/*.log`

**Q: No serial output after flashing**
- Check UART3 connection (not UART0)
- Verify baud: 1500000 (unusual but correct)
- See README.md "Troubleshooting" section

**Q: WiFi not connecting**
- Check SSID/password in config.env match your network
- SSH to board: `netplan apply`
- Check: `wpa_cli status`

See **README.md** for more troubleshooting

---

## 🎓 How It Works (Overview)

```
Windows Machine (You)          Ubuntu Server (Build)
    |                               |
    ├─ setup-validate.sh ──────────▶| (Checks SSH, disk space)
    |                               |
    ├─ config.env ─────────────────▶| (Read your settings)
    |                               |
    ├─ rk3308bs-evb.conf ──────────▶|
    |  + DTS + patch               | (Copy files)
    |                               |
    ├─ build-enhanced.sh ──────────▶| (Start build)
    |                               |
    |                        [Armbian Build]
    |                        ├─ Clone/update M1-SOC-Armbian-Build/ (persistent)
    |                        ├─ Apply your DTS patch
    |                        ├─ Create WiFi overlay
    |                        ├─ Create password script
    |                        ├─ Compile kernel
    |                        ├─ Package rootfs
    |                        └─ Create image
    |                               |
    |◀──── Download Image ──────────┤
    |
  [Image]
  ├─ Kernel with custom DTS
  ├─ WiFi pre-configured
  └─ Root password pre-set
```

---

## 📝 Files You Should Know

### `config.env`  -  Your Settings (EDIT THIS)
```bash
BUILD_SERVER_HOST="ubuntu-server"    # Where Armbian builds
BUILD_SERVER_USER="xateesix"
BUILD_SERVER_PATH="/home/xateesix/scratch/Projects/rk3308bs-workspace/M1-SOC-Armbian-Build"

WIFI_SSID="YOUR_WIFI_SSID"                   # Pre-configured in image
WIFI_PASSWORD="mNhTYTeh#..."

ROOT_PASSWORD="YOUR_PASSWORD"           # Pre-set in image
```

### `build-enhanced.sh`  -  Main Build Script (RUN THIS)
- Validates setup
- Copies files to server via SSH
- Creates WiFi overlay
- Creates password setup script
- Runs Armbian build
- Downloads image

### `setup-validate.sh`  -  Pre-Build Check (RUN THIS FIRST)
- Checks all files exist
- Verifies SSH works
- Checks disk space
- Tests server connectivity

### `rk3308bs-evb-amic-v11.dts`  -  Hardware Definition
- GPIO mappings
- LCD controller setup
- Audio codec (I2S)
- WiFi chip definition
- Touch screen
- USB ports
- Regulators
- **Don't edit unless you know hardware design**

---

## 🎯 Next Steps

1. ✅ **Read QUICKSTART.md** (3-step overview)
2. ✅ **Edit config.env** (set your server/WiFi/password)
3. ✅ **Run setup-validate.sh** (verify everything)
4. ✅ **Run build-enhanced.sh** (start build, wait 30 min)
5. ✅ **Flash image** (balenaEtcher recommended)
6. ✅ **Boot board** (WiFi auto-connects, SSH works immediately)

---

## 🆘 Need Help?

| Question | See |
|---|-----|
| How do I build? | **QUICKSTART.md** |
| What is each file? | **README.md**  ->  File Structure |
| Why did you change things? | **IMPROVEMENTS.md** |
| How do I set up GitHub? | **GITHUB_SETUP.md** |
| Build failed, what now? | **README.md**  ->  Troubleshooting |
| I want to modify DTS | **README.md**  ->  Advanced Usage |

---

## 📞 Support

- **Armbian Docs**: https://docs.armbian.com
- **Armbian Forum**: https://forum.armbian.com
- **Rockchip**: https://github.com/torvalds/linux/tree/master/arch/arm64/boot/dts/rockchip

---

## ✨ Key Insight

**This build system is designed around your feedback:**
- ✅ Persistent Armbian (not rebuilt every time)
- ✅ WiFi pre-configured (no manual setup)
- ✅ Root password automatic (no interactive prompt)
- ✅ Everything in one config file
- ✅ Single build script does it all

**You configure once, build many times. Future builds are fast.**

---

**Ready to build?  ->  Start with QUICKSTART.md** 🚀

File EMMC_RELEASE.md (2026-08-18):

# RK3308BS eMMC release pipeline

Repeatable path from Armbian build to monolithic RKDevTool flash image with
**custom rootfs** and **custom boot.img** (Phase B).

## Architecture

| Phase | boot.img | rootfs | Status |
|---|---|---|---|
| **B (default)** | Armbian 6.18 kernel (LZ4) + custom DTB in resource.img | Custom Armbian + hardware overlay | **Implemented** |
| **A (legacy)** | Factory LZ4 kernel + factory DTB (cmdline patch only) | Same rootfs + factory `8189fs.ko` inject | `--factory-kernel` |

Phase B builds a Rockchip-format `boot.img` from your Armbian `Image` and
`rk3308bs-evb-amic-v11.dtb`. Factory is used only for bootloader blobs
(MiniLoader, uboot, parameter) and as a **template** for `resource.img` layout.

## Prerequisites (one-time)

```bash
cd factory_fresh
chmod +x unpack-boot.sh
./unpack-boot.sh    # creates 04_boot_unpacked/resource.img template
```

Install in WSL: `lz4`, `python3`, `device-tree-compiler`, `e2fsprogs`.

## Workflow

### 1. Build Armbian (kernel + rootfs + DTB)

```bash
./build-enhanced.sh
```

Produces `../Armbian-unofficial_*_Rk3308bs-evb_bookworm_*.img`.

**Important:** After DTS changes, rebuild Armbian so the image contains an
updated `rk3308bs-evb-amic-v11.dtb` (recovered v67 uses `ttyS3`; older factory notes mention `ttyFIQ0`).

### 2. Pack monolithic eMMC update (Phase B default)

```bash
sudo -v
./build-emmc-release.sh \
  --armbian ../Armbian-unofficial_*_Rk3308bs-evb_bookworm_*.img \
  --version 1.0.0
```

Creates:
- `releases/1.0.0/boot.img`  -  Armbian kernel + your DTB
- `releases/1.0.0/rootfs.img`  -  your Armbian rootfs
- `releases/1.0.0/rk3308bs-1.0.0-emmc.img`  -  flash in RKDevTool

Options:
- `--factory-kernel`  -  Phase A (factory boot.img + 8189fs module extract)
- `--no-shrink`  -  skip `resize2fs -M`
- `--pack-only`  -  WSL staging only; run `windows-pack-update.ps1` on Windows

### 3. Flash

RKDevTool  ->  **Upgrade Firmware**  ->  `rk3308bs-1.0.0-emmc.img`

Serial: **UART3 @ 1500000**, console **`ttyS3`** on recovered v67 artifacts (older factory notes mention `ttyFIQ0`).

### 4. Verify

```bash
cat /etc/rk3308bs-release    # BOOT_PHASE=armbian-kernel-custom-rootfs
uname -r                     # 6.18.x-current-rockchip64
sudo ./RK3308_FACTORY_AUDIT.SH
```

## Phase B tools

| Tool | Purpose |
|---|---|
| `tools/build-armbian-bootimg.sh` | LZ4 kernel + resource.img + boot.img |
| `tools/pack-rockchip-bootimg.py` | Android boot image assembler |
| `tools/pack-resource-img.py` | Replace DTB inside factory resource.img template |
| `tools/extract-armbian-boot-artifacts.sh` | Pull Image + DTB from Armbian .img |

## WiFi (Phase B)

No factory `8189fs.ko` injection. WiFi comes from the **Armbian kernel**
(`rtl8189fs` / `8189fs.ko`) plus `firmware-realtek` matching rootfs
`/lib/modules/6.18.x-*`.

If WiFi fails after first boot, verify the RTL8189CS driver is enabled in the
Armbian kernel config and rebuild (`./build-enhanced.sh` or `./compile.sh kernel`).

## Legacy Phase A

```bash
./build-emmc-release.sh --factory-kernel --armbian ... --version 1.0.0
```

Uses factory kernel 5.10.160, `ttyFIQ0`, and optional factory module extract.

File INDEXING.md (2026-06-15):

# Indexed reference material (Cursor codebase indexing)

Updated: 2026-06-13

## In this repo (C:\Workspaces\Armbian-M1-SOC)

| Path | Purpose |
|---|---|
| factory_fresh/ | Factory partitions, DTS, EXTRACTION_SUMMARY |
| tools/ | Build/pack scripts, patch-parameter-boot-size.py |
| FLASH_GPT_DEBUG.md | GPT unnamed-partition boot failure analysis |
| FLASH_RKDEVTOOL.md | Flash procedure and log checks |
| RESUME_HERE.md | Session pickup |

Large binaries (*.img) are excluded from indexing but available via shell/WSL.

## Sibling reference repos (C:\Workspaces\reference)

| Path | Purpose |
|---|---|
| CB1/ | BTT CB1 README, system.cfg, overlays |
| BTT-build/ | BTT Armbian build fork (bpi-main) |

## Outside Workspaces (requires policy install)

| Path | Purpose |
|---|---|
| Downloads/RKDevTool_Release_v3.32/.../Log/ | Flash logs |
| .cursor/projects/c/agent-transcripts/ | Prior chat sessions |

## Activate indexing after policy update

1. PowerShell **as Administrator**: install.ps1
2. Cursor: Developer -> Reload Window
3. Cursor: Resync Index (or Settings -> Codebase Indexing -> Refresh)

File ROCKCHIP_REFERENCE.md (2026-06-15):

# Rockchip platform reference (factory vs public SDKs)

Updated: 2026-06-13

## Factory image (Artillery M1 Pro)  -  what we have

Extracted reference only (
actory_fresh/). **Original vendor SDK is not public.**

| Field | Factory value |
|---|---|
| Hostname | linaro-alip |
| OS | Debian 11 (bullseye) on Rockchip Linaro/ALIP-style rootfs |
| Kernel | 5.10.160  -  
k3308_linux_defconfig |
| DTB model | Rockchip RK3308B-S evb analog mic v11 board |
| Boot format | LZ4 kernel in Android oot.img + 
esource.img DTB bundle |
| Console | 	tyFIQ0 @ 1500000 (fiq-debugger / UART3) |
| Root | PARTUUID=614e0000-0000-4b53-8000-1d28000054a9 |
| GPT | Rockchip parameter.txt  -  
ootfs:grow at vendor offset |

Audit sources: 
k3308_system_audit/os_version.txt, .cursor/rk3308_factory_audit/

## What we do NOT have

- Artillery / Klipper vendor Linaro Linux SDK source (customized Rockchip BSP)
- Exact menson build tree that produced factory 5.10.160

## Closest public substitutes

Use these for **kernel defconfig, driver diff, partition layout, boot-chain patterns**  -  **not DTB/DTS** (factory only)  -  not as a drop-in replacement for Artillery userspace.

### Radxa (Rock Pi S  -  same RK3308)

| Resource | URL |
|---|-----|
| Kernel | https://github.com/radxa/kernel (stable, linux-5.10-gen-rkr8-* branches) |
| BSP tool | https://github.com/radxa/bsp  -  profile 
ock-pi-s |
| Docs | https://wiki.radxa.com/RockpiS |
| Defconfig | 
k3308_linux_defconfig (matches factory audit string) |
| DTB | 
k3308-rock-pi-s.dtb  -  compare with 
actory_fresh/05_dts/ |

Local images (Downloads, not indexed): 
ock-pi-s_debian_*, Armbian_*_Rockpi-s_*

### T-Firefly (ROC-RK3308B  -  same RK3308B silicon family)

| Resource | URL |
|---|-----|
| Wiki | https://wiki.t-firefly.com/en/ROC-RK3308B-CC-PLUS/linux_compile.html |
| SDK | Firefly_Linux_SDK via repo (
k3308_linux_release.xml) |
| Defconfig | 
irefly-rk3308b_linux_defconfig |
| DTS | 
k3308b-roc-cc-plus-amic_emmc  -  **closest public analog-mic EVB** |

Firefly and factory both use RK3308**B**-S EVB-style DTS naming (evb analog mic).

## How this project uses each source

| Need | Use |
|---|-----|
| Partition / flash / GPT | 
actory_fresh/03_partitions/ (ground truth for M1 Pro) |
| Serial / fiq-debugger / DTB | 
actory_fresh/05_dts/, factory audit |
| Kernel 6.18 + modules | Armbian build in this repo (uild-boot-v39.sh) |
| Rockchip boot.img pack | 	ools/stage-pack-v39.sh, patch-parameter-boot-size.py |
| Driver / DTS patterns (5.10) | Radxa kernel + Firefly DTS as **diff reference** |
| Embedded host UX (WiFi, system.cfg) | 
eference/CB1/, 
eference/BTT-build/ |

## Indexed paths

- 
actory_fresh/  -  Artillery factory blobs + DTS
- ../reference/BTT-build/  -  BTT Armbian fork
- ../reference/CB1/  -  CB1 docs
- This file + FLASH_GPT_DEBUG.md + INDEXING.md

## SDK download workflows (public)

### T-Firefly  -  repo-based SDK

Firefly publishes Rockchip BSPs via 
epo sync. The workflow is the same across SoCs; swap the manifest for RK3308:

| SoC | Manifest (example) | Wiki |
|-----|---|---|
| RK3588 | 
k3588_linux_release.xml | [Download Firefly_Linux_SDK](https://wiki.t-firefly.com/en/Core-3588J/linux_sdk_get.html) |
| RK3308B | 
k3308_linux_release.xml | [ROC-RK3308B compile](https://wiki.t-firefly.com/en/ROC-RK3308B-CC-PLUS/linux_compile.html) |

Typical init (RK3308B, from Firefly wiki):

`ash
mkdir -p ~/proj/rk3308_sdk && cd ~/proj/rk3308_sdk
repo init --no-clone-bundle \
  --repo-url https://gitlab.com/firefly-linux/git-repo.git \
  -u https://gitlab.com/firefly-linux/manifests.git \
  -b master -m rk3308_linux_release.xml
.repo/repo/repo sync -c --no-tags
`

BSP-only (smaller): 
k3308_linux_bsp_release.xml  -  device/rockchip, kernel, u-boot, rkbin, tools.

Requirements: Ubuntu 18.04 x86_64 host, normal user (not root). Same constraints as [Core-3588J SDK guide](https://wiki.t-firefly.com/en/Core-3588J/linux_sdk_get.html).

### Radxa  -  kernel repositories

| Repo | SoC / use |
|---|---|
| [radxa/kernel](https://github.com/radxa/kernel) | **RK3308 Rock Pi S**  -  stable, 
k3308_linux_defconfig (matches factory) |
| [radxa/linux-rockchip](https://github.com/radxa/linux-rockchip) | Older Radxa **Rock / Rock2** series  -  general Rockchip vendor-kernel patterns, not RK3308-specific |
| [radxa/bsp](https://github.com/radxa/bsp) | Modern build orchestration  -  profile 
ock-pi-s for RK3308 |

For M1 Pro (RK3308BS), prefer **radxa/kernel** + factory DTS diff. Use **linux-rockchip** only for legacy Rockchip driver/patch archaeology.

## DTB policy (hard rule)

Ship only factory-derived DTB from factory_fresh/04_boot_unpacked/resource.img, patched by patch-dtb-bootargs.py.

Radxa, Firefly, Rock Pi S, and generic Armbian DTBs are known not to work on the M1 Pro. Diff/reference only  -  never build inputs.

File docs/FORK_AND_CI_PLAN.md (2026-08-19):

# Fork upstream sources and GitHub CI plan

Companion firmware for Artillery M1 Pro X1 S1-SOC (RK3308BS). This document plans owning the full source stack: forks, patch queues, and automated rebuild on GitHub.

## Current pipeline (today)

```text
[Ubuntu build server]  build-enhanced.sh / Armbian compile.sh
        |  kernel patches (patches/*.patch) + board config + userpatches
        v
  rootfs-v61.img, _Image-v22, modules, uboot  -->  build-artifacts tarball
        |
[WSL / Windows]  tools/build-release-v64.sh
        |  boot DTB patches, rootfs debugfs, stage-pack, RKDevTool pack
        v
  rk3308bs-1.0.0-emmc-fixed-v64.img
```

The v64 line **repatches and repacks** GPL inputs; it does not recompile the kernel from zero unless inputs are regenerated on the build server.

## Target architecture

```text
                    +------------------+
                    |  This repo       |
                    |  M1-SOC-Armbian  |
                    |  - board DTS     |
                    |  - patches/      |
                    |  - userpatches   |
                    |  - tools/v64     |
                    |  - GitHub Actions|
                    +--------+---------+
                             |
         +-------------------+-------------------+
         |                   |                   |
         v                   v                   v
 +---------------+   +---------------+   +------------------+
 | fork:         |   | fork:         |   | fork (optional): |
 | armbian/build |   | linux stable  |   | rockchip rkbin   |
 |               |   | v6.18.y       |   | MiniLoader, etc. |
 +---------------+   +---------------+   +------------------+
```

### Repos to fork (under `xateesix` or org)

| Fork | Upstream | Role |
|---|---|---|
| `M1-SOC-armbian-build` | `github.com/armbian/build` | Image compile framework, `compile.sh`, board hooks |
| `M1-SOC-linux` | `github.com/gregkh/linux` branch `linux-6.18.y` | Kernel + our `patches/*.patch` as commits or quilt series |
| `M1-SOC-Armbian-Build` (existing private) | — | Board integration, v64 pack pipeline, docs, release scripts |
| `M1-SOC-Armbian-Build-scripts-public` (current public) | export of sanitized tree + Releases |

Optional: vendor `factory_fresh` partition templates in this repo or a small `M1-SOC-rk3308-factory` submodule (Rockchip loader binaries are redistributable per vendor terms; document provenance).

## Patch strategy

| Layer | Location today | Fork strategy |
|---|---|---|
| Kernel DTS + drivers | `patches/0001-0009`, `dts/` | Apply as git commits on `M1-SOC-linux` or export quilt series synced by CI |
| Armbian board | `rk3308bs-evb.conf`, `userpatches-*` | Pin in `M1-SOC-armbian-build` fork or copy into `userpatches/` on each sync |
| Boot DTB (display, lights) | `tools/patch-dtb-*.py`, `build-boot-v64.sh` | Stay in integration repo; inputs = kernel Image + factory resource |
| Rootfs companion | `patch-rootfs-public-credentials-debugfs.sh`, v64 debugfs | Stay in integration repo; public `m1prox1` / no WiFi |

**Rule:** forks hold **upstream-shaped** changes; integration repo holds **product** scripts (v64 pack, companion docs, release).

## GitHub Actions (proposed)

### Workflow 1: `sync-upstream.yml` (weekly + manual)

- Checkout forks with `actions/checkout`
- Subtree or scripted merge from upstream tags (`armbian` release branch, `linux-6.18.y`)
- Re-apply patch queue (fail PR if conflicts)
- Open auto-PR `upstream-sync-YYYY-MM-DD` for human review

### Workflow 2: `build-artifacts.yml` (self-hosted Linux runner)

**Runner:** same class as `10.22.2.208` Ubuntu (label `rk3308-builder`) with cached `armbian-build` tree.

```yaml
on:
  push:
    branches: [main]
  workflow_dispatch:

jobs:
  armbian-image:
    runs-on: [self-hosted, rk3308-builder]
    steps:
      - checkout integration repo
      - source config.env.public.example
      - ./build-enhanced.sh   # or compile.sh board target
      - tools/make-build-artifacts-tarball.sh v0.64.1
      - upload-artifact: build-artifacts-v0.64.1.tar.gz
```

### Workflow 3: `build-companion-image.yml` (Windows self-hosted or matrix)

**Runner:** Windows with RKDevTool v2.86 (`label: rk3308-pack`)

```yaml
  companion-v64:
    runs-on: [self-hosted, Windows, rk3308-pack]
    needs: armbian-image
    steps:
      - download build-artifacts tarball
      - bash tools/rebuild-from-scratch-v64.sh   # WSL on runner
      - upload-artifact: rk3308bs-1.0.0-emmc-fixed-v64.img (or split if >2GB)
```

### Workflow 4: `release.yml` (on tag `v*`)

- Attach tarball + `.img` to GitHub Release on **public** repo (or private staging first)
- Run `tools/push-to-public.sh` for source-only export
- **Gate:** manual approval / only after test flash job passes

### Secrets

| Secret | Use |
|---|-----|
| `BUILD_SSH_KEY` | self-hosted runner registration |
| `DISCORD_WEBHOOK_URL` | optional build notify (private repo only) |

No WiFi or user passwords in CI — use `config.env.public.example` only.

## Migration phases

### Phase 1 — Now (local)

- [x] `tools/rebuild-from-scratch-v64.sh` — clean v64 rebuild from `rootfs-v61-private.bak` + public credentials
- [x] `tools/patch-rootfs-public-credentials-debugfs.sh` — no-sudo public bake
- [ ] Flash-test image before any Release upload
- [ ] Commit integration scripts + `docs/FORK_AND_CI_PLAN.md`

### Phase 2 — Forks

1. Fork `armbian/build` and `linux` on GitHub
2. Push kernel patches as commits; tag `m1pro-v6.18.1-r1`
3. Document `BRANCH` / `KERNELBRANCH` pins in `config.env.example`
4. Set `FETCH_ARMBIAN_SOURCE=1` / `FETCH_KERNEL_SOURCE=1` to clone forks instead of upstream

### Phase 3 — Self-hosted CI

1. Register Ubuntu builder + Windows pack runner
2. Implement `build-artifacts.yml` + artifact cache
3. Implement companion pack job with RKDevTool v2.86 path

### Phase 4 — Upstream sync automation

1. `sync-upstream.yml` with conflict PRs
2. Optional: Dependabot-style weekly kernel stable tag check

## File size / Release constraints

- Monolithic `.img` is ~6.4 GB — **exceeds GitHub single-asset 2 GB limit**
- Options: self-hosted release mirror, split download, Git LFS + billing, or OCI bucket (S3/R2) with Release linking URL only

Plan: CI uploads tarball to release; `.img` hosted on external mirror until GitHub Large File Storage or chunking is configured.

## Local commands (maintainer)

```bash
# Full v64 from scratch (public credentials, all v64 patches)
bash tools/rebuild-from-scratch-v64.sh

# Full Armbian recompile (Ubuntu server)
./build-enhanced.sh

# Public export (no firmware in git)
bash tools/push-to-public.sh
```

## Open decisions

1. **Org vs personal forks** — single `xateesix` org for all forks?
2. **Kernel line** — stay on 6.18.y vs track Armbian `current` branch?
3. **Image hosting** — where to put 6 GB `.img` for public users?
4. **Test gate** — manual flash checklist vs automated hardware test runner?

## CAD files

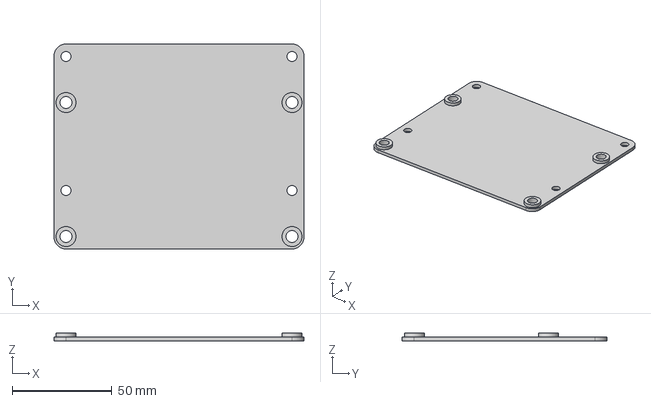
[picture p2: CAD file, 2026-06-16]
models/M1-PowerSupply-Relocate.step
125.0 x 102.5 x 4.00 mm

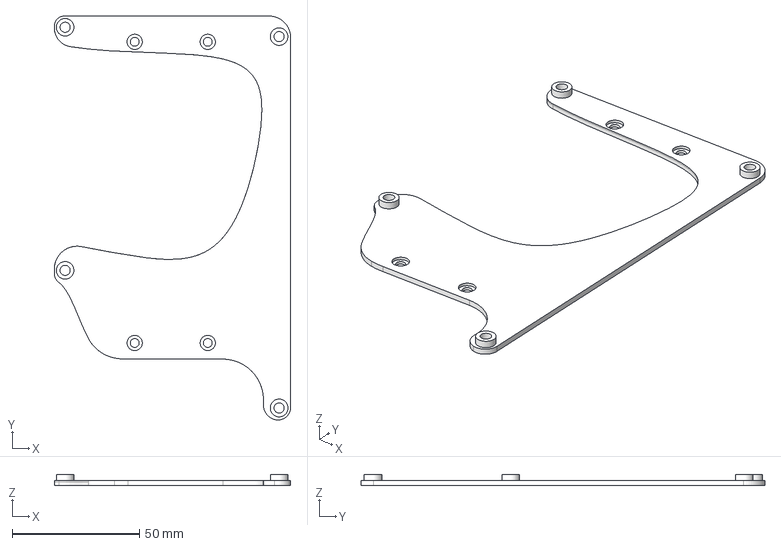
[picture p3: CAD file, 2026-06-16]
models/M4P_M1Pro_Mounting_bracket.step
93.0 x 159.0 x 4.50 mm

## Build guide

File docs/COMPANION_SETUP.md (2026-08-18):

# Companion setup: KlipperScreen + Crowsnest on the S1-SOC

The factory **S1-SOC** (this Armbian image) is a **secondary host**. It does **not** run Klipper for printer motion. It runs **KlipperScreen** and **Crowsnest** and talks to the **main Klipper host** (e.g. BTT Manta M4P + FYSETC H36) over the network.

Decouple UI and camera from the main instance: Moonraker stays on the motion stack; the companion only serves display and webcam streams.

**Status:** the image build now stages the companion stack at compile time. The build pulls KIAUH, Klipper, Moonraker, KlipperScreen, and Crowsnest source trees into `/opt/rk3308bs/companion-stack`, then seeds a starter `KlipperScreen.conf` and a companion-stack manifest under `/etc/rk3308bs`.

## Prerequisites

| Item | Where |
|---|---|
| Main Klipper + **Moonraker** running | Motion host (Manta M4P, etc.) |
| Companion image flashed | S1-SOC eMMC (`rk3308bs-1.0.0-emmc-fixed-v64.img`) |
| Same LAN | Both hosts reachable (WiFi or Ethernet) |
| Webcam (for Crowsnest) | USB camera on **companion** or routed as your build requires |

Note the **IP addresses**:

- `<MAIN_HOST_IP>`  -  Manta / Moonraker (example `192.168.1.50`)
- `<COMPANION_IP>`  -  S1-SOC (example `192.168.1.51`)

## Step 1: KlipperScreen on the companion (S1-SOC)

KlipperScreen only needs the **Moonraker API**. Do **not** install a Klipper MCU stack on the S1-SOC for printer control.

1. Review `/etc/rk3308bs/companion-stack.env` on the companion.
2. Install or finish wiring the stack using the staged source trees under `/opt/rk3308bs/companion-stack/repos`.
3. Edit KlipperScreen config (seeded into `/etc/skel/.config/KlipperScreen.conf` during build, and commonly copied into `~/.config/KlipperScreen.conf` after first boot).
4. Point at the **main** Moonraker instance:

```ini
[printer M1ProX1]
moonraker_host: <MAIN_HOST_IP>
moonraker_port: 7125
```

5. Restart KlipperScreen. The **480x272** panel on the S1-SOC should show telemetry and controls for the printer on the motion host.

Multi-printer / remote Moonraker patterns: [KlipperScreen documentation](https://github.com/KlipperScreen/KlipperScreen) and guides on controlling multiple printers via Moonraker host settings.

## Step 2: Crowsnest on the companion (S1-SOC)

Crowsnest is an independent streaming server. It can run on the second host with **no Klipper** on that host.

References: [Running crowsnest on an external device (Mainsail Crew #2252)](https://github.com/orgs/mainsail-crew/discussions/2252)

1. Use the staged `crowsnest` source tree under `/opt/rk3308bs/companion-stack/repos/crowsnest` or install via KIAUH if you prefer its workflow.
2. Edit `/etc/crowsnest.conf` on the **companion**  -  camera device, resolution, and stream port (commonly **8080**).
3. Start or restart Crowsnest and confirm the stream is live:

```text
http://<COMPANION_IP>:8080/webcam/?action=stream
```

## Step 3: Point Mainsail / Fluidd at the companion stream

Your **web UI runs on the main host** (or your usual browser target). Add the companion camera as an **external** webcam URL.

1. Open **Mainsail** or **Fluidd** (connected to Moonraker on `<MAIN_HOST_IP>`).
2. **Settings**  ->  **Webcams**  ->  add camera.
3. Stream URL:

```text
http://<COMPANION_IP>:8080/webcam/?action=stream
```

4. Save and refresh the dashboard.

The motion host serves Klipper/Moonraker; the companion serves video. Same pattern as multi-camera setups with a separate streaming device.

## Summary

```text
  [ Manta M4P + H36 ]          LAN          [ S1-SOC companion ]
  Klipper + Moonraker  <----------------->  KlipperScreen  ->  Moonraker API
       :7125                                  Crowsnest     ->  :8080 stream
       Mainsail/Fluidd  ----browser---->  webcam URL = COMPANION_IP:8080
```

## Related docs

- [`UPGRADE_PATH.md`](UPGRADE_PATH.md)  -  motion stack (Manta + H36)
- [`README.md`](README.md)  -  project overview
- [`SERIAL_CONSOLE.md`](SERIAL_CONSOLE.md)  -  debug without display/WiFi

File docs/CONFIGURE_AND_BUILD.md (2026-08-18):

# Configure and build (v0.64.1)

Companion image for S1-SOC (KlipperScreen + Crowsnest). Motion Klipper runs on Manta/H36.

During build, the pipeline also bakes in the custom boot logo and stages companion software source trees (KIAUH, Klipper, Moonraker, KlipperScreen, Crowsnest) under `/opt/rk3308bs/companion-stack`.

```bash
./configure.sh
bash setup-validate.sh
bash tools/build-release-v64.sh
```

After flash, see [`COMPANION_SETUP.md`](COMPANION_SETUP.md) for Moonraker/Crowsnest wiring.

See [`README.md`](README.md) and [`FLASH_RKDEVTOOL.md`](FLASH_RKDEVTOOL.md).

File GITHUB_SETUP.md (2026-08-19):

# GitHub Setup for Cross-Device Collaboration

If you want to sync your Armbian build setup across devices or collaborate, use GitHub.

## One-Time Setup

### 1. Create GitHub Repository

Go to https://github.com/new

- **Repository name**: `rk3308bs-armbian` (or your preference)
- **Private**: [OK] (recommended for board configs)
- **Initialize with**: None (we'll push our files)

Copy the HTTPS URL: `https://github.com/YOUR_USER/rk3308bs-armbian.git`

### 2. Initialize Git in Armbian Folder

```bash
cd Armbian

# Initialize
git init

# Add all files
git add -A

# Commit
git commit -m "Initial RK3308BS Armbian firmware setup"

# Add remote (use your repo URL)
git remote add origin https://github.com/YOUR_USER/rk3308bs-armbian.git

# Push to GitHub
git branch -M main
git push -u origin main
```

### 3. Update Build Script (Optional)

If using GitHub, add this to `build-enhanced.sh` for automatic GitHub sync:

```bash
# After successful build, push to GitHub
if [ -n "$GITHUB_REPO" ] && git -C "$SCRIPT_DIR" rev-parse --git-dir >/dev/null 2>&1; then
    cd "$SCRIPT_DIR"
    git add -A
    git commit --allow-empty -m "Build $(date +%Y-%m-%d_%H:%M:%S): WiFi=$WIFI_SSID kernel=6.18.35"
    git push origin main || warn "GitHub push failed (network?)"
fi
```

---

## Using on Build Server

### Clone on Ubuntu Server

```bash
ssh xateesix@ubuntu-server

# Clone your Armbian config repo
cd /tmp
git clone https://github.com/YOUR_USER/rk3308bs-armbian.git rk3308bs-conf

# Symlink into Armbian build
cd /home/xateesix/scratch/Projects/rk3308bs-workspace/M1-SOC-Armbian-Build
ln -sf /tmp/rk3308bs-conf/userpatches/* userpatches/ 2>/dev/null || true
ln -sf /tmp/rk3308bs-conf/config/boards/* config/boards/ 2>/dev/null || true

# Done! Now all your overlays and board config is active
```

### Keep Sync'd

```bash
cd /tmp/rk3308bs-conf
git pull  # Get latest from your machine
```

---

## Collaborative Workflow

**You (Windows machine):**
```bash
cd Armbian
# Edit config.env or DTS
git add -A
git commit -m "Update WiFi config"
git push origin main
```

**Build server automatically syncs:**
```bash
ssh xateesix@ubuntu-server
cd /tmp/rk3308bs-conf && git pull
# Changes now live in /home/xateesix/scratch/Projects/rk3308bs-workspace/M1-SOC-Armbian-Build
```

---

## Alternative: Push Build Outputs

To also store images in GitHub (if <100MB):

```bash
# In Armbian folder
git add Armbian-*_rk3308bs-evb*.img
git commit -m "Build output $(date)"
git push origin main
```

⚠️ For larger images, use GitHub Releases instead:
https://docs.github.com/en/repositories/releasing-projects-on-github/managing-releases-in-a-repository

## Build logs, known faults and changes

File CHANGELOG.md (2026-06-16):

# Changelog

## v0.64.1 (2026-06-16)
- Fix m1prox1 home ownership; remove legacy xateesix home/group
- Disable systemd ANSI on framebuffer boot console (tty0)
- Plain-text MOTD branding
- Credential bake: subuid/subgid, home chown, WiFi scrub

## v0.64.1 (2026-06-15)
- Public release: interactive configure.sh, documentation, GPIO hardware map
- Case light bar pin GPIO2_B3 confirmed; RGB deferred
- eMMC pipeline build-release-v64.sh

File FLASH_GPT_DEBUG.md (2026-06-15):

# Flash / GPT debug notes (RK3308BS M1 Pro)

Updated: 2026-06-13

## Symptom

After wipe + full v45 flash (rk3308bs-1.0.0-emmc-fixed-v45.img):

- Boot GPT: boot @ 0xe800 size 0x8a00 (correct)
- Part 6 @ 0x17200 size 0xe28e00 NO NAME (wrong - expect rootfs @ 0x311800)
- Kernel cmdline: PARTUUID=614e0000-0000-4b53-8000-1d28000054a9 + console=ttyFIQ0
- Panic: VFS Unable to mount root fs on PARTUUID

## RKDevTool log (good full flash)

- total=1677655552, Gpt=1
- rootfs offset=0x17200 size=1647312896 (~47-48 sec)

Bad partial flash: total=30342656, no rootfs line.

## Root cause hypothesis

v45 parameter.txt uses explicit: 0x00311800@0x00017200(rootfs)
Factory uses grow: -@0x00013000(rootfs:grow) + uuid:rootfs=614e0000-...

RKDevTool v3.32 writes rootfs data but on-device GPT is unnamed grow 0xe28e00.
Without name rootfs, uuid:rootfs line may not bind PARTUUID.

## Fix (v46 planned)

Use -@0x00017200(rootfs:grow) in patch-parameter-boot-size.py (factory pattern).

## Indexed references

- factory_fresh/03_partitions/parameter.txt
- ../reference/CB1/ and ../reference/BTT-build/
- Downloads/RKDevTool_Release_v3.32/.../Log/

## v46 fix applied

- stage-pack-v39.sh: removed `--rootfs` explicit size
- parameter: `-@0x00017200(rootfs:grow)` + uuid:rootfs
- Image: `rk3308bs-1.0.0-emmc-fixed-v46.img` ({now})

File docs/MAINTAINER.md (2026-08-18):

# Maintainer notes (private workflow)

## Dual repository workflow

| Remote | Purpose |
|---|---|
| **Private** (`origin`) | Full development tree, probe scripts, local configs |
| **Public** (`public`) | Sanitized export for community use |

```bash
git push origin main              # private: all work
bash tools/push-to-public.sh      # public: scrubbed export
```

Set `PRIVATE_REPO_URL` and `PUBLIC_REPO_URL` in `config.env`.

Discord build notifications (`tools/notify-discord.sh`) read `DISCORD_WEBHOOK_URL` from `config.env` and are **not** exported to the public repo.

## Public export safety

- Treat `config.env`, logs, serial captures, and release binaries as private-only unless explicitly sanitized.
- Before publishing, redact usernames, passwords, API keys, Wi-Fi SSIDs/PSKs, IP addresses, hostnames, and device identity data.
- Keep the public repository limited to sanitized source, templates, and approved release artifacts.
- Assume the workspace is unstable and may close at any time; preserve durable notes in tracked files, not live session state.

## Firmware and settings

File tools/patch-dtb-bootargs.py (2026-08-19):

#!/usr/bin/env python3
"""Set /chosen/bootargs on a DTB (Rockchip U-Boot uses this, not boot.img cmdline)."""
from __future__ import annotations

import argparse
import shutil
import struct
import subprocess
import sys
from pathlib import Path


def patch_with_fdtput(
    dtb: Path,
    bootargs: str,
    out: Path,
    stdout_path: str = "",
) -> None:
    fdtput = shutil.which("fdtput")
    if not fdtput:
        raise FileNotFoundError("fdtput not found (install device-tree-compiler)")

    tmp = out
    if out.resolve() != dtb.resolve():
        tmp.write_bytes(dtb.read_bytes())

    subprocess.check_call(
        [fdtput, "-t", "s", str(tmp), "/chosen", "bootargs", bootargs],
    )
    if stdout_path:
        subprocess.check_call(
            [fdtput, "-t", "s", str(tmp), "/chosen", "stdout-path", stdout_path],
        )


def compile_dts_source(dts: Path, out: Path, kernel_root: Path | None = None) -> None:
    """Compile a DTS source to a compact DTB so the final blob stays under the Rockchip resource slot."""
    cpp = shutil.which("cpp")
    dtc = shutil.which("dtc")
    if not cpp or not dtc:
        raise FileNotFoundError("cpp/dtc not found (install device-tree-compiler)")

    if kernel_root is None:
        candidates = [
            Path("/home/xateesix/scratch/Projects/rk3308bs-workspace/M1-SOC-Armbian-Build/cache/sources/linux-kernel-worktree"),
            Path("/home/xateesix/scratch/Projects/rk3308bs-workspace/M1-SOC-Armbian-Build/cache/sources/linux-kernel-worktree"),
        ]
        found = None
        for cand in candidates:
            if cand.exists():
                for child in sorted(cand.iterdir()):
                    if (child / "arch/arm64/boot/dts/rockchip/rk3308.dtsi").exists():
                        found = child
                        break
                if found is not None:
                    break
        if found is None:
            raise FileNotFoundError(
                "Could not locate linux-kernel-worktree with arch/arm64/boot/dts/rockchip/rk3308.dtsi; "
                "pass --kernel-root or compile from a binary DTB."
            )
        kernel_root = found

    pre = out.with_suffix(".pre.dts")
    try:
        with pre.open("wb") as pre_fh:
            subprocess.check_call(
                [
                    cpp,
                    "-nostdinc",
                    "-undef",
                    "-D__DTS__",
                    "-x",
                    "assembler-with-cpp",
                    "-I",
                    str(kernel_root / "arch/arm64/boot/dts"),
                    "-I",
                    str(kernel_root / "arch/arm64/boot/dts/rockchip"),
                    "-I",
                    str(kernel_root / "include"),
                    str(dts),
                ],
                stdout=pre_fh,
            )
        subprocess.check_call(
            [
                dtc,
                "-I",
                "dts",
                "-O",
                "dtb",
                "-o",
                str(out),
                "-i",
                str(kernel_root / "arch/arm64/boot/dts"),
                "-i",
                str(kernel_root / "arch/arm64/boot/dts/rockchip"),
                "-i",
                str(kernel_root / "include"),
                str(pre),
            ],
        )
    finally:
        if pre.exists():
            pre.unlink()


def extract_factory_dtb(resource: Path) -> bytes:
    data = resource.read_bytes()
    old_size, off = _find_fdt_slot(data)
    return data[off : off + struct.unpack(">I", data[off + 4 : off + 8])[0]]


def _remove_dts_subnode(text: str, name: str) -> str:
    """Remove a child node block like 'display-timings { ... };' from DTS source."""
    needle = f"{name} {{"
    start = text.find(needle)
    if start < 0:
        return text
    line_start = text.rfind("\n", 0, start) + 1
    depth = 0
    i = text.find("{", start)
    while i < len(text):
        ch = text[i]
        if ch == "{":
            depth += 1
        elif ch == "}":
            depth -= 1
            if depth == 0:
                end = i + 1
                while end < len(text) and text[end] in " \t":
                    end += 1
                if end < len(text) and text[end] == ";":
                    end += 1
                if end < len(text) and text[end] == "\n":
                    end += 1
                return text[:line_start] + text[end:]
        i += 1
    return text


def patch_rk3308_panel_dpi(dtb: Path) -> None:
    """Use upstream panel-dpi + panel-timing instead of legacy simple-panel binding."""
    dtc = shutil.which("dtc")
    if not dtc:
        raise FileNotFoundError("dtc not found (install device-tree-compiler)")

    dts = dtb.with_suffix(".panel.dts")
    subprocess.check_call([dtc, "-I", "dtb", "-O", "dts", "-o", str(dts), str(dtb)], stderr=subprocess.DEVNULL)
    text = dts.read_text()
    if 'compatible = "simple-panel"' in text:
        text = text.replace('compatible = "simple-panel"', 'compatible = "panel-dpi"', 1)
    text = _remove_dts_subnode(text, "display-timings")
    timing_block = (
        "\t\tpanel-timing {\n"
        "\t\t\tclock-frequency = <0x895440>;\n"
        "\t\t\thactive = <0x1e0>;\n"
        "\t\t\tvactive = <0x110>;\n"
        "\t\t\thback-porch = <0x2b>;\n"
        "\t\t\thfront-porch = <0x08>;\n"
        "\t\t\tvback-porch = <0x0c>;\n"
        "\t\t\tvfront-porch = <0x08>;\n"
        "\t\t\thsync-len = <0x04>;\n"
        "\t\t\tvsync-len = <0x04>;\n"
        "\t\t\thsync-active = <0x01>;\n"
        "\t\t\tvsync-active = <0x01>;\n"
        "\t\t\tde-active = <0x00>;\n"
        "\t\t\tpixelclk-active = <0x01>;\n"
        "\t\t};\n"
    )
    if "panel-timing {" not in text:
        panel_idx = text.find("panel {")
        if panel_idx < 0:
            raise RuntimeError("panel node not found in decompiled DTS")
        port_idx = text.find("port {", panel_idx)
        if port_idx < 0:
            raise RuntimeError("panel port node not found in decompiled DTS")
        line_start = text.rfind("\n", panel_idx, port_idx) + 1
        text = text[:line_start] + timing_block + text[line_start:]
    dts.write_text(text)
    subprocess.check_call(
        [dtc, "-I", "dts", "-O", "dtb", "-o", str(dtb), str(dts), "-Wno-unit_address_vs_reg"],
    )
    dts.unlink(missing_ok=True)
    print(
        "  panel compatible=panel-dpi panel-timing=480x272@9MHz "
        "(removed display-timings; bus-format unchanged on /panel)"
    )


def patch_goodix_factory_defaults(dtb: Path) -> None:
    fdtget = shutil.which("fdtget")
    fdtput = shutil.which("fdtput")
    if not fdtget or not fdtput:
        raise FileNotFoundError("fdtget/fdtput not found")

    candidates = [
        "/i2c@ff070000/goodix_ts@5d",
        "/i2c@ff070000/touchscreen@5d",
    ]
    node = None
    for cand in candidates:
        rc = subprocess.call(
            [fdtget, str(dtb), cand, "compatible"],
            stdout=subprocess.DEVNULL,
            stderr=subprocess.DEVNULL,
        )
        if rc == 0:
            node = cand
            break

    if node is None:
        print("  goodix node not found, skipping factory defaults")
        return

    subprocess.check_call([fdtput, "-t", "i", str(dtb), node, "touchscreen-size-x", "800"])
    subprocess.check_call([fdtput, "-t", "i", str(dtb), node, "touchscreen-size-y", "480"])

    for prop, value in (("max-x", "800"), ("max-y", "480")):
        rc = subprocess.call(
            [fdtget, str(dtb), node, prop],
            stdout=subprocess.DEVNULL,
            stderr=subprocess.DEVNULL,
        )
        if rc == 0:
            subprocess.check_call([fdtput, "-t", "i", str(dtb), node, prop, value])

    print("  goodix: size=800x480 (factory GPIO flags preserved)")


def _find_fdt_slot(data: bytes) -> tuple[int, int]:
    magic = b"\xd0\x0d\xfe\xed"
    candidates: list[tuple[int, int]] = []
    offset = 0
    while True:
        idx = data.find(magic, offset)
        if idx < 0:
            break
        if idx + 8 <= len(data):
            totalsize = struct.unpack(">I", data[idx + 4 : idx + 8])[0]
            if 64 <= totalsize <= len(data) - idx:
                candidates.append((totalsize, idx))
        offset = idx + 4
    if not candidates:
        raise SystemExit("No FDT magic found")
    totalsize, off = max(candidates, key=lambda x: x[0])
    slot_end = off + totalsize
    while slot_end < len(data) and data[slot_end] == 0 and (slot_end - off) <= 65536:
        slot_end += 1
    return slot_end - off, off


def main() -> int:
    ap = argparse.ArgumentParser(description=__doc__)
    ap.add_argument("--dtb", type=Path, help="Input DTB (not needed with --from-factory-resource or --dts)")
    ap.add_argument("--dts", type=Path, help="Optional source .dts to compile first so the DTB stays compact enough for the resource slot")
    ap.add_argument("--kernel-root", type=Path, help="Optional linux-kernel-worktree root used to resolve include files when compiling --dts")
    ap.add_argument("--output", required=True, type=Path)
    ap.add_argument(
        "--console",
        default="",
        help="console= value (default: ttyFIQ0 with --from-factory-resource, else ttyS3,1500000n8)",
    )
    ap.add_argument(
        "--root-uuid",
        default="614e0000-0000-4b53-8000-1d28000054a9",
        help="rootfs GPT PARTUUID from parameter.txt uuid:rootfs=",
    )
    ap.add_argument("--bootargs", default="", help="Full bootargs override")
    ap.add_argument(
        "--stdout-path",
        default=None,
        help="/chosen/stdout-path (default: skip for factory DTB, else serial3:1500000n8)",
    )
    ap.add_argument(
        "--from-factory-resource",
        type=Path,
        help="Extract rk-kernel.dtb from factory resource.img instead of --dtb",
    )
    ap.add_argument(
        "--armbian-serial",
        action="store_true",
        help="Legacy: disable fiq-debugger and use ttyS3 (do not use on RK3308BS  -  console is ttyFIQ0)",
    )
    ap.add_argument(
        "--disable-thermal-critical",
        action="store_true",
        help="Downgrade soc-crit trip to passive at 120C",
    )
    ap.add_argument(
        "--rk3308bs-tsadc",
        action="store_true",
        help="Set tsadc compatible to rockchip,rk3308bs-tsadc (needs kernel patch 0002)",
    )
    ap.add_argument(
        "--disable-tsadc",
        action="store_true",
        help="Disable tsadc node in DTB as an emergency workaround for early thermal resets",
    )
    ap.add_argument(
        "--rk3308-vop-resets",
        action="store_true",
        help="Add CRU resets (axi/ahb/dclk) to vop@ff2e0000 (rockchipdrm bind needs ahb reset)",
    )
    ap.add_argument(
        "--rk3308-panel-dpi",
        action="store_true",
        help="Panel: panel-dpi + panel-timing (480x272@9MHz) for Linux 6.18 DRM",
    )
    ap.add_argument(
        "--goodix-factory-defaults",
        action="store_true",
        help="Force Goodix IRQ active-low and touchscreen size to 800x480",
    )
    args = ap.parse_args()

    src = args.dtb
    if args.dts:
        src = args.output.with_suffix(".compiled.dtb")
        compile_dts_source(args.dts, src, kernel_root=args.kernel_root)
        print(f"Compiled DTS ({args.dts}) -> DTB ({len(src.read_bytes())} bytes)")
    if args.from_factory_resource:
        blob = extract_factory_dtb(args.from_factory_resource)
        src = args.output.with_suffix(".extracted.dtb")
        src.write_bytes(blob)
        print(f"Extracted factory DTB ({len(blob)} bytes) from {args.from_factory_resource}")
    elif not src:
        ap.error("Provide --dtb, --dts, or --from-factory-resource")

    console = args.console
    if not console:
        if args.armbian_serial or not args.from_factory_resource:
            console = "ttyS3,1500000n8"
        else:
            console = "ttyFIQ0"

    stdout_path = args.stdout_path
    if stdout_path is None:
        stdout_path = "serial3:1500000n8" if args.armbian_serial or not args.from_factory_resource else ""

    if args.bootargs:
        bootargs = args.bootargs
    else:
        bootargs = (
            f"earlycon=uart8250,mmio32,0xff0d0000 console={console} "
            f"root=PARTUUID={args.root_uuid} rootfstype=ext4 rw rootwait"
        )

    try:
        patch_with_fdtput(
            src,
            bootargs,
            args.output,
            stdout_path=stdout_path,
        )
        if args.armbian_serial:
            fdtput = shutil.which("fdtput")
            if not fdtput:
                raise FileNotFoundError("fdtput not found")
            subprocess.check_call(
                [fdtput, "-t", "s", str(args.output), "/fiq-debugger", "status", "disabled"],
            )
            subprocess.check_call(
                [fdtput, "-t", "s", str(args.output), "/serial@ff0d0000", "status", "okay"],
            )
            print("  fiq-debugger=disabled serial@ff0d0000=okay (Armbian ttyS3 console)")
        if args.disable_thermal_critical:
            fdtput = shutil.which("fdtput")
            if not fdtput:
                raise FileNotFoundError("fdtput not found")
            crit = "/thermal-zones/soc-thermal/trips/soc-crit"
            subprocess.check_call(
                [fdtput, "-t", "s", str(args.output), crit, "type", "passive"],
            )
            subprocess.check_call(
                [fdtput, "-t", "i", str(args.output), crit, "temperature", "120000"],
            )
            print("  soc-crit=passive @ 120C")
        if args.rk3308bs_tsadc:
            fdtput = shutil.which("fdtput")
            if not fdtput:
                raise FileNotFoundError("fdtput not found")
            subprocess.check_call(
                [
                    fdtput,
                    "-t",
                    "s",
                    str(args.output),
                    "/tsadc@ff1f0000",
                    "compatible",
                    "rockchip,rk3308bs-tsadc",
                ],
            )
            print("  tsadc@ff1f0000 compatible=rockchip,rk3308bs-tsadc")
        if args.disable_tsadc:
            fdtput = shutil.which("fdtput")
            if not fdtput:
                raise FileNotFoundError("fdtput not found")
            subprocess.check_call(
                [fdtput, "-t", "s", str(args.output), "/tsadc@ff1f0000", "status", "disabled"],
            )
            print("  tsadc@ff1f0000 status=disabled")
        if args.rk3308_vop_resets:
            fdtput = shutil.which("fdtput")
            if not fdtput:
                raise FileNotFoundError("fdtput not found")
            # SRST_VOP_A/H/D = 38/39/40; cru phandle = 2 in factory DTB
            subprocess.check_call(
                [
                    fdtput,
                    "-t",
                    "i",
                    str(args.output),
                    "/vop@ff2e0000",
                    "resets",
                    "2",
                    "38",
                    "2",
                    "39",
                    "2",
                    "40",
                ],
            )
            subprocess.check_call(
                [
                    fdtput,
                    "-t",
                    "s",
                    str(args.output),
                    "/vop@ff2e0000",
                    "reset-names",
                    "axi",
                    "ahb",
                    "dclk",
                ],
            )
            print("  vop@ff2e0000 resets=SRST_VOP_A/H/D reset-names=axi,ahb,dclk")
        if args.rk3308_panel_dpi:
            patch_rk3308_panel_dpi(args.output)
        if args.goodix_factory_defaults:
            patch_goodix_factory_defaults(args.output)
    except FileNotFoundError as exc:
        print(exc, file=sys.stderr)
        return 1

    print(f"Wrote {args.output}")
    print(f"  bootargs={bootargs!r}")
    return 0


if __name__ == "__main__":
    sys.exit(main())

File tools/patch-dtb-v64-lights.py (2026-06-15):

#!/usr/bin/env python3
"""v64: PWM0 lightbar with pwm0-pin pinctrl fix on factory RK3308 DTB.

Light bar: LED +/- header, PWM0 @ ff160000 (GPIO0_B5 / gpio line 13).
NeoPixel DATA: GPIO0_A1 (gpio line 1) on 3-pin header  -  userspace test script.
"""
from __future__ import annotations

import argparse
import re
import shutil
import subprocess
import sys
from pathlib import Path


def _run(cmd: list[str]) -> None:
    subprocess.check_call(cmd)


def decompile(dtb: Path, dts: Path) -> None:
    _run(["dtc", "-I", "dtb", "-O", "dts", "-o", str(dts), str(dtb)])


def compile_dts(dts: Path, dtb: Path) -> None:
    _run(
        [
            "dtc", "-I", "dts", "-O", "dtb", "-o", str(dtb), str(dts),
            "-Wno-unit_address_vs_reg", "-Wno-graph_child_address",
        ]
    )


def _remove_subnode(text: str, name: str) -> str:
    needle = f"{name} {{"
    start = text.find(needle)
    if start < 0:
        return text
    line_start = text.rfind("\n", 0, start) + 1
    depth = 0
    i = text.find("{", start)
    while i < len(text):
        if text[i] == "{":
            depth += 1
        elif text[i] == "}":
            depth -= 1
            if depth == 0:
                end = i + 1
                while end < len(text) and text[end] in " \t":
                    end += 1
                if end < len(text) and text[end] == ";":
                    end += 1
                if end < len(text) and text[end] == "\n":
                    end += 1
                return text[:line_start] + text[end:]
        i += 1
    return text


def _trim_bloat(text: str) -> str:
    for node in ("bluetooth-sound", "spdif-rx-sound", "spdif-tx-sound"):
        text = _remove_subnode(text, node)
    text = text.replace('\t\t\tdefault-state = "on";\n', "")
    return text


def _label_pwm0(text: str) -> str:
    if re.search(r"^\s*pwm0:\s*pwm@ff160000", text, re.M):
        return text
    return re.sub(r"(\s*)pwm@ff160000\s*\{", r"\1pwm0: pwm@ff160000 {", text, count=1)



def _fix_pwm0_pinctrl(text: str) -> str:
    """Factory DTB points pwm@ff160000 at pwm8-pin (GPIO2_A10). Use GPIO0_B5."""
    if "pwm0-pin-active" in text:
        return text
    old = "\n\t\t\tpwm0-pin {\n\t\t\t\trockchip,pins = <0x00 0x0d 0x01 0x83>;\n\t\t\t};"
    new = old + "\n\n\t\t\tpwm0-pin-active {\n\t\t\t\trockchip,pins = <0x00 0x0d 0x01 0x83>;\n\t\t\t\tphandle = <0x100>;\n\t\t\t};"
    if old not in text:
        raise RuntimeError("pwm0-pin node not found")
    text = text.replace(old, new, 1)
    m = re.search(r"(pwm0:\s*pwm@ff160000\s*\{)(.*?)(\n\t\};)", text, re.S)
    if not m:
        m = re.search(r"(pwm@ff160000\s*\{)(.*?)(\n\t\};)", text, re.S)
    if not m:
        raise RuntimeError("pwm@ff160000 node not found")
    head, inner, tail = m.group(1), m.group(2), m.group(3)
    inner = re.sub(r"pinctrl-0\s*=\s*<[^>]+>\s*;", "pinctrl-0 = <0x100>;", inner, count=1)
    return text[: m.start()] + head + inner + tail + text[m.end() :]
def _enable_pwm0(text: str) -> str:
    m = re.search(r"(pwm0:\s*pwm@ff160000\s*\{)(.*?)(\n\t\};)", text, re.S)
    if not m:
        m = re.search(r"(pwm@ff160000\s*\{)(.*?)(\n\t\};)", text, re.S)
    if not m:
        raise RuntimeError("pwm@ff160000 node not found")
    head, inner, tail = m.group(1), m.group(2), m.group(3)
    if 'status = "okay"' not in inner:
        inner = re.sub(r'status\s*=\s*"disabled"\s*;', 'status = "okay";', inner, count=1)
        if 'status = "okay"' not in inner:
            inner = inner.rstrip() + '\n\t\tstatus = "okay";'
    return text[: m.start()] + head + inner + tail + text[m.end() :]


def _insert_lightbar(text: str) -> str:
    if "lightbar:white" in text:
        return text
    node = (
        "\n\tlightbar {\n"
        "\t\tcompatible = \"pwm-leds\";\n"
        "\t\tled-bar {\n"
        "\t\t\tlabel = \"lightbar:white\";\n"
        "\t\t\tpwms = <&pwm0 0 10000 0>;\n"
        "\t\t};\n"
        "\t};\n\n"
    )
    marker = '\n\tleds {\n\t\tcompatible = "gpio-leds";'
    if marker not in text:
        raise RuntimeError("root gpio-leds node not found")
    return text.replace(marker, node + marker, 1)


def patch(text: str) -> str:
    text = _trim_bloat(text)
    text = _label_pwm0(text)
    text = _fix_pwm0_pinctrl(text)
    text = _enable_pwm0(text)
    text = _insert_lightbar(text)
    return text


def main() -> int:
    ap = argparse.ArgumentParser(description=__doc__)
    ap.add_argument("--dtb", required=True, type=Path)
    ap.add_argument("--output", required=True, type=Path)
    args = ap.parse_args()
    if not shutil.which("dtc"):
        print("error: dtc not found", file=sys.stderr)
        return 1
    dts = args.output.with_suffix(".lights.dts")
    decompile(args.dtb, dts)
    patched = patch(dts.read_text())
    dts.write_text(patched)
    compile_dts(dts, args.output)
    dts.unlink(missing_ok=True)
    print(f"v64 lights DTB: {args.output} ({args.output.stat().st_size} bytes)")
    return 0


if __name__ == "__main__":
    raise SystemExit(main())

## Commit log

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2026-04-23 armbian-resize-filesystem: fix typo $rootdev → $diskdev
    $rootdev is undefined in do_expand_partition; should be $diskdev.
    Fixes #9594
    Assisted-by: Claude:claude-opus-4-7
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2026-04-24 helios64: u-boot: bump v2026.01 → v2026.04
    Self-contained board_helios64/ overlay bumped to v2026.04 from v2026.01.
    The overlay is a pristine copy of v2026.01 plus the minimum set of
    v2026.04-mandated changes and new cherry-picks:
    - board/Kconfig: ENV_OFFSET 0x460000 → 0x3F8000
    Required by the v2026.04 SPI NOR environment layout.
    - 1001-fdt_fixup_ethernet-add-logs.patch.disabled
    Cherry-pick of Ricardo Pardini's fdt_fixup_ethernet logging patch.
    Shipped disabled; preserved for debugging MAC propagation issues.
    - cmd-fileenv-read-string-from-file-into-env.patch
    Cherry-pick of the Home Assistant 2018 vendor patch (rebased by
    rpardini) adapting 'fileenv' u-boot command for v2026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
2026-04-24 helios64: defensive fixes on top of u-boot v2026.04 bump
    Code-style and defensive-programming fixes to the helios64 u-boot
    overlay, applied on top of the pristine v2026.04 vendor bump. All
    changes are additive safety nets — none alter the happy-path
    behaviour of the previous Kobol/Armbian code.
    board/helios64.c:
    - setup_leds(): check led_get_by_label() return value. Without
    this, led_set_state() is called on an uninitialised udevice
    pointer if LED lookup fails.
    - sata_power_enable(): add the matching 10s mdelay after
    enabling hdd_b_power, mirroring the one already present after
    hdd_a_power. Previously rail B had no spin-up time before
    scsi_scan(true) in last_stage_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
2026-04-24 u-boot: v2026.04: add btrfs zstd decompression fix
    Same fix as #9651 for v2026.01 and v2025.10, applied to the common
    patch/u-boot/v2026.04/ directory so all boards on U-Boot v2026.04 pick
    it up (cm3588-nas, nanopct6, orangepi5, rock-3a, nanopi-r3s-lts,
    mekotronics-*, mixtile-blade3, radxa-rock-4d, helios64 via its own
    self-contained board_helios64 subdir already has a copy).
    Without this, booting from a BTRFS rootfs with zstd-compressed extents
    fails with:
    zstd_decompress: failed to decompress: 70
    BTRFS: An error occurred while reading file /boot/boot.scr
    See commit 5617ff3fd for the full rationale.
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2026-05-01 patch: disable drm/xe patches that don't apply to current kernels (NEEDS FIXING)
    Rename two .patch files to .patch.NEED_FIX so the patch driver
    skips them on apply. Both are drm/xe kernel patches that stopped
    applying cleanly after an upstream rebase and haven't been
    refreshed yet:
    - 0002-drm-xe-guc-use-GUC_SIZE-SZ_4K-for-alignment.patch
    - 0005-drm-xe-query-use-PAGE_SIZE-as-the-minimum-page-align.patch
    Kernels that were picking these up need them re-based against
    current upstream drm/xe before re-enabling. Not a behaviour
    change on its own — the patches were already failing the apply
    step — but stops the noise in build logs and makes it obvious
    at a glance which patches need mainta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
2026-05-02 validate-board-config: follow `source ${SRC}/config/boards/<foo>` inheritance
    `Validate changed board configs` (PR #9747 CI run 25258999953) failed
    on the three Ayn-Odin2 derivative boards with:
    ERROR: config/boards/ayn-odin2mini.csc: BOARDFAMILY: required, ...
    ERROR: config/boards/ayn-odin2mini.csc: KERNEL_TARGET: required, ...
    (same pair on ayn-odin2portal.csc and ayn-thor.csc)
    The validator's header explicitly says it does NOT source the file
    ("boards have side-effecty function bodies"), and the regex
    `parse_assignments` only sees top-level `KEY=value` lines. Boards
    that consist of one `source "${SRC}/config/boards/<parent>.csc"` line
    plus a handful of overrides (BOARD_NAME,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
2026-05-03 fix: rename imx8m bare uboot hook so binman pkg_resources patch can run
    `imx8m.conf` defined a bare `pre_config_uboot_target()`. The framework
    treats a bare hook as the full implementation and drops any
    `pre_config_uboot_target__<purpose>` companions, so #9407's
    auto-enabled `uboot-binman-fix-pkg-resources` extension was never
    firing on i.MX 8M boards — `tools/binman/control.py`'s
    `import pkg_resources` stayed unpatched, and `make flash.bin` died
    with `ModuleNotFoundError` on Python 3.12 / setuptools >= 82.
    Rename to `pre_config_uboot_target__imx8m_firmware()`. Body unchanged.
    Both hooks now register and run; order between them doesn't matter
    (NXP firmware fetch vs. Python source rewrite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
2026-05-03 fix: switch rockchip family_tweaks from addgroup to groupadd
    `addgroup` lives in `adduser`, which Debian forky no longer pulls
    into a minimal rootfs by default. `family_tweaks` then dies with
    `bash: line 1: addgroup: command not found` (exit 127) on every
    forky-armhf rockchip build.
    `groupadd` is in `passwd` (Essential, every Linux), and works
    identically for our use here. The only behavioural difference —
    `groupadd` returns 9 if the group already exists where `addgroup`
    returns 0 — is gated by the existing `getent group … ||` guard in
    rockchip.conf, and added to rockchip-rv1106.conf to keep
    re-runnability.
    Repro: armbian/os tinkerboard-current forky-armhf, log
    https://paste.armbian.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
2026-05-05 rk35xx-montjoie-crypto-v2: struct sm3_state → struct sm3_ctx SM3 API reworked in 7.1 (struct sm3_ctx now used for export/import).
2026-05-05 bleedingedge: disable broken wifi drivers - rtl8189es, rtl8723ds: pppoe_hdr/pppoe_tag members removed - rtl8852bs, uwe5622: cfg80211 net_device* -> wireless_dev* conversion - uwe5622: of_gpio.h remov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
2026-05-05 Add support for Photonicat2 board with USB hub watchdog
    - Introduced a USB hub watchdog service to fix USB quirk for photonicat2
    - Updated U-Boot version to v2026.04 for photonicat2
    - Add maintainer information for photonicat2
2026-05-05 fix(config): skip host filesystem compatibility check for ROOTFS_TYPE=nfs
    The check_filesystem_compatibility_on_host() call in do_main_configuration()
    greps /proc/filesystems for $ROOTFS_TYPE and modprobes it if missing,
    aborting the build when neither succeeds. For ROOTFS_TYPE=nfs (and the
    new nfs-root variant added by the netboot extension) this fires falsely:
    the build never mounts NFS on the host. rootfs-to-image.sh produces a
    tarball via 'tar | gzip' and lets the target's kernel mount NFS at boot
    time. Host NFS support is concept-level irrelevant for these rootfs types.
    The check also misbehaves under docker-launcher: /lib/modules is not
    forwarded into the container, so even when the h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
2026-05-05 image/compress-checksum: maximize CPU + memory use
    Replace static `xz -T 0` / `zstdmt -9` with a CPU- and memory-aware
    share so a single runner alone on a big box uses every core, peers
    share fairly without OOMing each other, and small sibling artefacts
    don't reserve per-thread memory they can't use.
    Threads = full nproc (kernel time-slices when peer xz/zstd jobs contend;
    we get the cores when they idle). Memory is fair-shared among peers:
    budget = MemAvailable * 0.6 / (active+1).
    The level walk requires BOTH a memory ceiling and a CPU floor — without
    the floor, a 2-core ARM box with a few GB free would have escalated to
    xz -6 / zstd -22 --ultra, which is much heavier on weak CPUs than t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
2026-05-05 feat(boards/helios4): enable watchdog extension by default
    The Helios4 board ships with the Marvell Armada 388 hardware watchdog
    (orion_wdt) but no userspace kicker is configured in the default image.
    After a kernel oops the machine stays hung instead of being reset.
    Enable the existing 'watchdog' extension (already used by helios64,
    odroidm1, odroidn2): adds the 'watchdog' Debian package to the rootfs
    and uncomments watchdog-device in /etc/watchdog.conf, so the watchdog
    daemon (or wd_keepalive fallback) opens /dev/watchdog and keeps the
    hardware timer alive. A wedged kernel will then trigger a hardware
    reset within ~60s instead of requiring a manual power-cycle.
    Tested on Helios4 with ker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
2026-05-05 chore(config/common): remove dead FAST_CREATE_IMAGE variable
    Declared in config/sources/common.conf since 2022-11 (RISC-V import,
    commit 9edad5194) but never read anywhere in the build. Removing the
    zombie declaration to avoid suggesting the framework has a 'fast image
    creation' switch that users could enable.
    Confirmed dead by repo-wide grep (only the declaration itself matches)
    and by GitHub code-search across armbian/build.
2026-05-05 fix(kernel/rockchip64-7.0): restore SysRq-via-BREAK on dw-apb-uart (8250_dw)
    Sending a serial BREAK followed by a SysRq command character stopped
    working on dw-apb-uart (e.g. RK3399 / helios64) in linux-7.0.y.
    The refactor that introduced the regression replaced the explicit
    uart_unlock_and_check_sysrq_irqrestore() in serial8250_handle_irq()
    with a guard(uart_port_lock_irqsave) scope. The guard releases the
    port lock at scope exit, but does NOT check port->sysrq_ch and
    therefore never calls handle_sysrq().
    Other 8250-family drivers (amba-pl011, meson_uart, msm_serial, ...)
    each call uart_unlock_and_check_sysrq() explicitly in their IRQ
    handler; 8250_dw relied on serial8250_handle_irq() doi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
2026-05-05 docker: gate --privileged behind DOCKER_PRIVILEGED toggle (default yes)
    Adds DOCKER_PRIVILEGED env var (default "yes" for backward compatibility).
    Set DOCKER_PRIVILEGED=no to launch the build container without --privileged,
    instead complementing the existing --cap-add=SYS_ADMIN/MKNOD/SYS_PTRACE
    and loop-related --device-cgroup-rule entries with:
    --device=/dev/loop-control:/dev/loop-control
    --security-opt=seccomp=unconfined
    The original justifications for --privileged (USB FEL, raw block-device
    write via CARD_DEVICE) no longer apply: FEL was removed in 86db860a52,
    and CARD_DEVICE is now passed via --device=${CARD_DEVICE}.
    The losetup helper later in the same function still uses --privil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
2026-05-05 docker: gate image cleanup behind DOCKER_PRUNE=yes (default off)
    docker_cli_prepare() called docker_cleanup_old_images
    unconditionally, which enumerates 'docker images' and rmi's old
    armbian tags. Fine on a single-daemon workstation; broken on
    hosts where several build framework invocations share one
    dockerd — the usual setup when multiple self-hosted GH Actions
    runners live on the same machine.
    Two concurrent invocations race: runner A's cleanup fires
    'docker rmi <id>' on a tag runner B just committed between
    'Successfully built <sha>' and dockerd writing the imagedb
    digest file. B's build then aborts with:
    Successfully built ed6bcbe445e6
    failed to get digest sha256:ed6bcbe445e6…: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
2026-05-05 Quote variables in destructive commands (#9400 P0) (#9401)
    * extensions: image-output-abl: quote variables in destructive commands (#9400 P0)
    Quote all variable expansions passed to rm, mount, umount, losetup,
    mkfs, sed -i, cp, truncate, blkid, gzip, cat, e2fsck, resize2fs, and
    source to prevent word splitting. Replace `[ ! -z ]` with `[[ -n ]]`.
    * extensions: uwe5622-allwinner: quote variables in destructive commands (#9400 P0)
    Quote $SDCARD in chroot calls and $destination, $SRC, ${ARCH} in
    cp, mkdir, and install commands to prevent word splitting.
    * extensions: cloud-init: quote variables in destructive commands (#9400 P0)
    Quote ${config_src}, $config_dst, ${defaults_src}, $defaults_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
2026-05-06 fix(kernel/mvebu-6.18): restore SysRq-via-BREAK on dw-apb-uart (8250_dw)
    The mvebu kernel uses the same dw-apb-uart driver (drivers/tty/serial/8250/8250_dw.c)
    on Armada 388 / 38x SoCs as RK3399 does, and inherits the same SysRq-via-BREAK
    regression introduced by the guard(uart_port_lock_irqsave) refactor that PR #9750
    fixes for kernel-rockchip64-7.0.
    Verified on helios4 (Armada 388, kernel-mvebu 6.18-edge) 2026-05-05:
    - Without patch: BREAK + 'h' through picocom is consumed by the IRQ handler
    (port->sysrq_ch is latched correctly), but uart_unlock_and_check_sysrq_irqrestore()
    is never called from the handler tail, so handle_sysrq() never runs.
    - With patch: BREAK + 'h' produces '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
2026-05-06 action: emit assets manifest JSON alongside release uploads (#9772)
    * action: emit assets manifest JSON alongside release uploads
    Adds a step to the composite action that walks build/output/images
    after build, parses each image filename, reads board metadata from the
    build framework's existing output/info/image-info.json, optionally
    enriches per-board fields by fetching the canonical
    github.armbian.com/armbian-images.json (Bigin-resolved company info,
    platinum status, and a fallback for board_* metadata), and writes one
    '<image_filename>.assets.json' next to each artefact. The existing
    release-action glob picks the manifests up automatically — no caller
    change needed.
    Schema mirrors the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
2026-05-07 pci: pcie_dw_rockchip: increase PCIe retry count for Rock 5B cold boot
    On RK3588 (Rock 5B), NVMe drives fail to enumerate after a cold boot
    (complete power loss) because the PCIe link does not train within the
    original 10-retry / 1s window. Warm boots succeed because the NVMe
    retains power and is already initialized when LTSSM starts.
    Increase the retry count from 10 to 25 (2.5s total at 100ms per retry).
    The pre-PERST stabilization delay remains at 100ms so warm-boot
    performance is unaffected — the extra time is only consumed when the
    link fails to come up on the first few attempts, which only occurs on
    a cold boot where the NVMe needs time to stabilize after power-on.
    Tested on Rock 5B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
2026-05-07 panther-x2: move from CSC to EOS
    The .eos suffix marks the board as end-of-support; rebuilds are
    skipped from the auto-generated release matrices. File contents are
    unchanged — pure rename.
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2026-05-08 u-boot v2026.04: add UFS support for RK3576
    Y. Charkov's UFS v5 series (Kwiboo/u-boot ufs-v5, not yet upstream), a
    Linux mainline DT cherry-pick, and a controller hard-reset workaround.
    Moved up from board_radxa-rock-4d/ since the SPL gap is SoC-wide.
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2026-05-08 nanopi-m5: add kernel DT patches (current/edge/bleedingedge)
    Replaces checked-in DTS copies with branch-specific patches against
    upstream. Enables RTL8822CS Wi-Fi, Bluetooth, GMAC RGMII delays, ADC
    back button, UART3/UART8. 6.18 also enables &ufshc + regulators.
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2026-05-08 helios4: bump u-boot to v2026.04 (#9786)
    Patches forked from board_helios4/v2025.10/ to board_helios4/v2026.04/;
    all 9 apply (5 with rebase fuzz, left as follow-up).
    Patch 0005 'arm-mvebu-helios4-Update-Load-address' is carried as
    .disabled. Its vendor 2013 layout (kernel/initrd gap=8 MiB,
    KERNEL_ADDR_R=0x2080000) was the source of "RD image overlaps
    OS image" PXE failures with modern zImage 6.12+; upstream defaults
    (KERNEL=0x800000, RAMDISK=0x1800000, gap=16 MiB) work fine.
    boot-mvebu.cmd already runtime-overrides ramdisk_addr_r to
    0x03080000, so SD-flow remains unaffected.
    Validated by SD-boot of resolute armhf 6.18.27-edge-mvebu image
    on real Helios4: u-boot 2026.04, btrfs root, mvneta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
2026-05-09 desktops: replace legacy config/desktop/ tree with armbian-config module_desktops
    Desktop builds no longer synthesise a per-DE, per-release, per-appgroup
    package list from config/desktop/*/environments/*/config_base/packages
    plus config/desktop/*/appgroups/*/packages. Instead, rootfs-create.sh
    calls `armbian-config --api module_desktops install de=$DESKTOP_ENVIRONMENT
    tier=$DESKTOP_TIER mode=build` inside the chroot, and armbian-config's
    YAML-driven module_desktops assembles the install from its
    tools/modules/desktops/yaml/*.yaml definitions at build time.
    * config/desktop/ tree (hundreds of config_base/packages, postinst,
    create_desktop_package.sh, architectures, support files) is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
2026-05-09 targets-compositor: add tiers + skip/only-arches to items-from-inventory
    Two orthogonal knobs for userspace blocks in
    userpatches/targets-*.yaml:
    * tiers: [minimal, mid, full]
    Emit one item per tier for every matched (release, arch,
    desktop) triple. armbian-config's module_desktops treats
    minimal / mid / full as separate install targets with
    different package sets, so they can't share a rootfs
    artifact — they need separate matrix items. Default stays
    ['mid'] so pre-existing targets that don't know about this
    knob keep producing one userspace per desktop, same as
    before. Targets that want the full fan-out set
    'tiers: [minimal, mid, fu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
2026-05-09 desktops: backwards-compat for legacy DESKTOP_APPGROUPS_SELECTED
    The tier model (minimal / mid / full) subsumes the old per-group
    package axis — 'full' already includes everything the old
    appgroups provided (office, multimedia, programming, chat,
    remote_desktop, desktop_tools, editors, email, internet).
    Userpatches and board configs in the wild still set
    DESKTOP_APPGROUPS_SELECTED, and silently ignoring it would
    produce a thinner desktop than the user expects. Map it to
    tier=full when DESKTOP_TIER isn't set explicitly, with one
    carve-out: the sentinel 'none' (meaning 'base DE, no extras')
    is treated as empty — the user didn't actually pick any
    appgroups, so don't upgrade them to tier=fu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
2026-05-09 artifact-rootfs: stop forcing SKIP_ARMBIAN_REPO=yes; default to no
    artifact_rootfs_cli_adapter_config_prep set SKIP_ARMBIAN_REPO=yes
    unconditionally, which made sense when rootfs assembly only
    needed the distro archive. It doesn't anymore: the new desktop
    install path runs 'armbian-config --api module_desktops install
    mode=build' from inside rootfs-create.sh (see earlier commit in
    this PR), and armbian-config itself lives in the <release>-utils
    component of apt.armbian.com, with firefox / chromium / GNOME
    branding in <release>-desktop.
    With SKIP_ARMBIAN_REPO=yes forced on, the install step would hit
    'E: Unable to locate package armbian-config' at rootfs-create
    time for every desktop build.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
2026-05-09 rootfs cache: refresh configng every build; fingerprint tier + hash into cache_type
    Two bugs that conspired to make 'new configng commit but still
    served the old rootfs from cache' the default behaviour.
    1. The fetch_from_repo for armbian-configng was gated inside the
    '[[ -z $DESKTOP_ENVIRONMENT ]]' branch of
    interactive_desktop_main_configuration, so it only fired when
    the user picked a DE from the interactive dialog. Every
    non-interactive build (CI, items-from-inventory, scripted
    local with DESKTOP_ENVIRONMENT= pre-set) skipped the fetch —
    which left whatever stale clone happened to live in
    cache/sources/armbian-configng/ as the source of truth for
    the CONFIGNG_D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
2026-05-09 bsp-cli: drop stale chromium rescue block + orphaned desktop blobs
    Three lines in armbian-bsp-cli's postinst:
    if [[ -L "/usr/lib/chromium-browser/master_preferences.dpkg-dist" ]]; then
    mv /usr/lib/chromium-browser/master_preferences.dpkg-dist /usr/lib/chromium-browser/master_preferences
    fi
    shipped in 2018 (commit 2b6dad1ea) alongside
    packages/bsp/common/usr/lib/chromium-browser/master_preferences.dpkg-dist,
    as the tail half of a rescue pattern that dealt with chromium-browser's
    conffile clashing with an armbian-supplied symlink/preseed file.
    The ship-side half was removed long ago — bsp-cli no longer packages
    anything under /usr/lib/chromium-browser/ — so the -L test is never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
2026-05-10 (#9400 P1b) Replace unsafe eval with declare -g and nameref (#9461)
    * (#9400 P1b) cli: utils-cli: replace eval with declare -g
    eval "declare -g $name=\"$value\"" is equivalent to the safer
    declare -g "${name}=${value}" which avoids code injection risk.
    * (#9400 P1b) configuration: interactive: replace eval with declare -g
    Two eval calls in set_interactive_config_value():
    - eval "$1"='$2' → declare -g "${1}=${2}"
    - eval "ARMBIAN_INTERACTIVE_CONFIGS[${1}]"='$2' → direct array assignment
    * (#9400 P1b) configuration: change-tracking: replace eval with nameref
    The origina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
2026-05-10 kernel-dtb: surface skipped preprocessed-DTS step in output (fixes #8083)
    When BOOT_FDT_FILE is unset, kernel_dtb_only_build() still produces the
    linux-dtb .deb (from `make dtbs` + dtbs_install) but the convenience
    preprocessed-DTS copy into output/ is skipped. The previous warn-level
    message was easy to miss, which is what led to the original report of
    "no output of the preprocessed dts files".
    Change the skip message to err-level and spell out that the package
    itself is fine and point at both likely config sources.
2026-05-11 Disable: SpacemiT: fix RX DMA params not set when TX is running
    Landed upstream
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2026-06-12 Update RK3308BS build scripts and configurations: change image tag to v28, enhance WiFi and display module dependencies, add support for LCD configuration, and implement VOP resets in device tree pat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
    [gen-panel-simple-patch.py, patch-dtb-bootargs.py]
2026-06-12 Refactor RK3308BS build scripts: update image tag to v28, enhance WiFi and display module dependencies, add LCD configuration support, and implement VOP resets in device tree patching. Improve kernel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
    [gen-panel-simple-patch.py]
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2026-06-13 Enhance RK3308BS build and configuration scripts: update gen-patch-0007.py to improve panel supply error handling, modify gen-patch-0007.sh to prevent abort on diff errors, and refine install-kernel-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
    [gen-patch-0007.py, gen-patch-0008.py]
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2026-06-13 Refactor patch-rootfs-v45-mount.sh to improve sudo handling and add cross-chroot setup. Introduce run_root function for consistent command execution with or without sudo, and implement setup_cross_ch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
    [patch-parameter-boot-size.py]
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2026-06-15 Refactor patch-rootfs-v45-mount.sh to enhance error handling and streamline command execution. Introduce run_root function for consistent sudo usage, and implement setup_cross_chroot and teardown_cro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
    [_deploy_remote.py, _patch-v57-bootstatus.py, _patch-v57-display.py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]
2026-06-15 Refactor patch-rootfs-v45-mount.sh to improve error handling and streamline command execution. Enhance the run_root function for consistent sudo usage, and refine setup_cross_chroot and teardown_cros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
    [neopixel-pin-sweep.py, patch-dtb-v64-lights.py]
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2026-06-15 Fix UTF-8 mojibake across docs; add dual-repo public export workflow
    Replace corrupted en-dash/arrow/box-drawing with ASCII in 58 files.
    Add configure source fetch, install-build-deps, push-to-public.sh.
    Private origin keeps full tree; public remote gets sanitized export.
    [patch-dtb-bootargs.py, patch-dtb-v62-lights.py, patch-dtb-v63-lights.py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]
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2026-06-16 Sync public README edits, add required 3D bracket models, fix public push auth.
    [M1-PowerSupply-Relocate.step, M4P_M1Pro_Mounting_bracket.step]
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2026-08-19 v76: Complete build-pack-canon integration - all learnings canonicalized
    Discovered & documented complete 6-stage pipeline (was missing stages 5-6)
    Recovered v69-v75 releases to canonical /pack/releases/ location
    Created hard rule for output location integrity
    Packed v76 as RKFW blob (1.7GB, checksum verified)
    Uploaded to flashpc with transfer verification
    Integrated 100% of learning into canon documentation
    Created master index for new agents
    New canon:
    - CANON-INTEGRATION-INDEX.md (master reference)
    - PACKING-AND-FLASHING-CANON.md (stages 5-6)
    - SESSION-LEARNING-V76-PACK.md (learning summary)
    - SESSION-V76-STATUS.md (current status)
    - FINAL-SESSION-SUMMARY.md (session summary)
    - INTEGRATI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
    [patch-dtb-bootargs.py]
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
